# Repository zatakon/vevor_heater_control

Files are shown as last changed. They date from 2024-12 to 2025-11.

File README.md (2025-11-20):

# Vevor Heater Control
Vevor diesel heater control project

---

>## ⚠️ IMPORTANT: You Probably Want the Other Repository!
>
>**This repository is for protocol reverse engineering and research purposes only.**
>
>**If you want a ready-to-use ESPHome library for your Vevor heater, please visit:**
>### 👉 **[https://github.com/zatakon/esphome-vevor-heater](https://github.com/zatakon/esphome-vevor-heater)** 👈
>
>The `esphome-vevor-heater` repository contains a complete, user-friendly ESPHome custom component that you can easily integrate into your Home Assistant setup.

---

## Background

I bought a Vevor diesel heater and put it into my workshop with the intention to keep the temperature above zero during winter. There is a project for communication with Chinese heaters, but this broadly used protocol is unfortunately not used in Vevor ones. Because there was no solution on how to connect Vevor to my Home Assistant ecosystem, I needed to do it by myself.

## 2. Current Status of the Project
The project is now ready to use for all who have some experience with ESPHome. 

### 2.1 HW
This is a simple schematic of how I connected my ESP32 to the bus. \
Be careful and connect the RX transistor to the 3.3V rail, not 5V. \
**Double check the transistors'** pinout. \
Feel free to use any pin for TX and RX. \
**Put pullup resistor between data line and 5V**

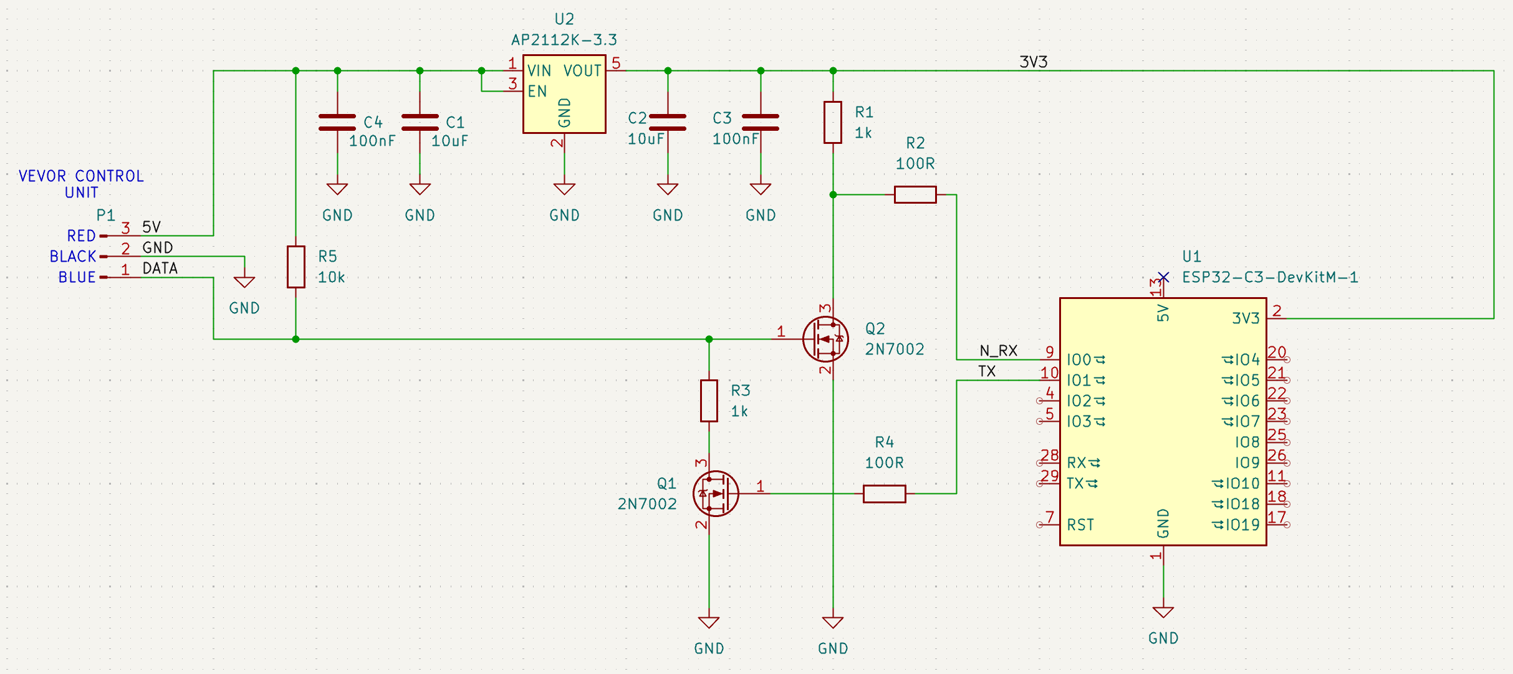
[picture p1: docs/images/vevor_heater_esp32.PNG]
Connection ESP32 to Vevor


### 2.2 SW

1. Open terminal in project folder
```
firmware/esphome/vevor_heater_example
```

2. Install the ESPHome library using pip
```
pip install esphome
```
3. Change the config RNW-ESPHM-C3-MNM-VEVOR/RNW-ESPHM-C3-MNM-VEVOR.yaml to match your board configuration and just run it using this command
```bash
esphome run vevor_heater_example
```

The project for my board is located in the folder firmware/esphome/RNW-ESPHOME-C3-MNM-VEVOR. There are more settings than you need and no temperature sensor. Add one if you want to. 

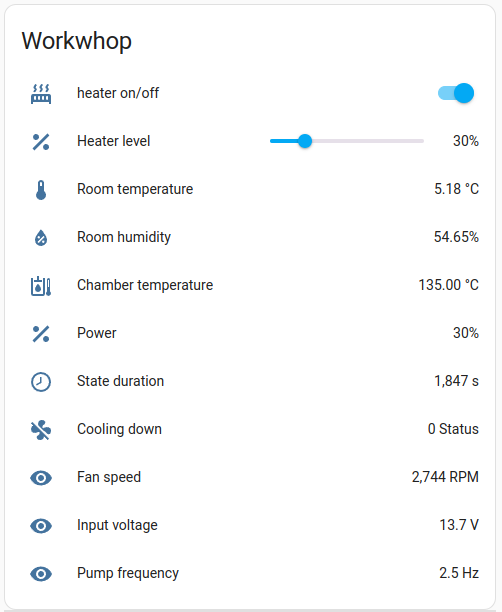
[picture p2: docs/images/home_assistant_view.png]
ESPhome view

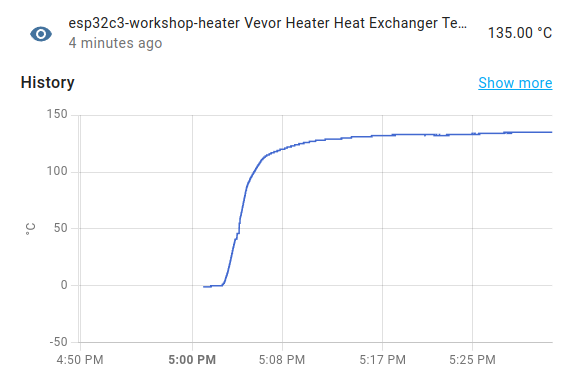
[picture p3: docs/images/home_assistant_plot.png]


A more easy-to-use solution is in the "work in progress" state. I will try to get to it soon. 

## 4. Hardware background
The bus is open drain. The basic voltage is approximately 4V and very noisy (3.3 - 6V). Don't connect directly to any MCU without protection; there is a risk that the magic smoke will escape...

Captured communication looks like this:
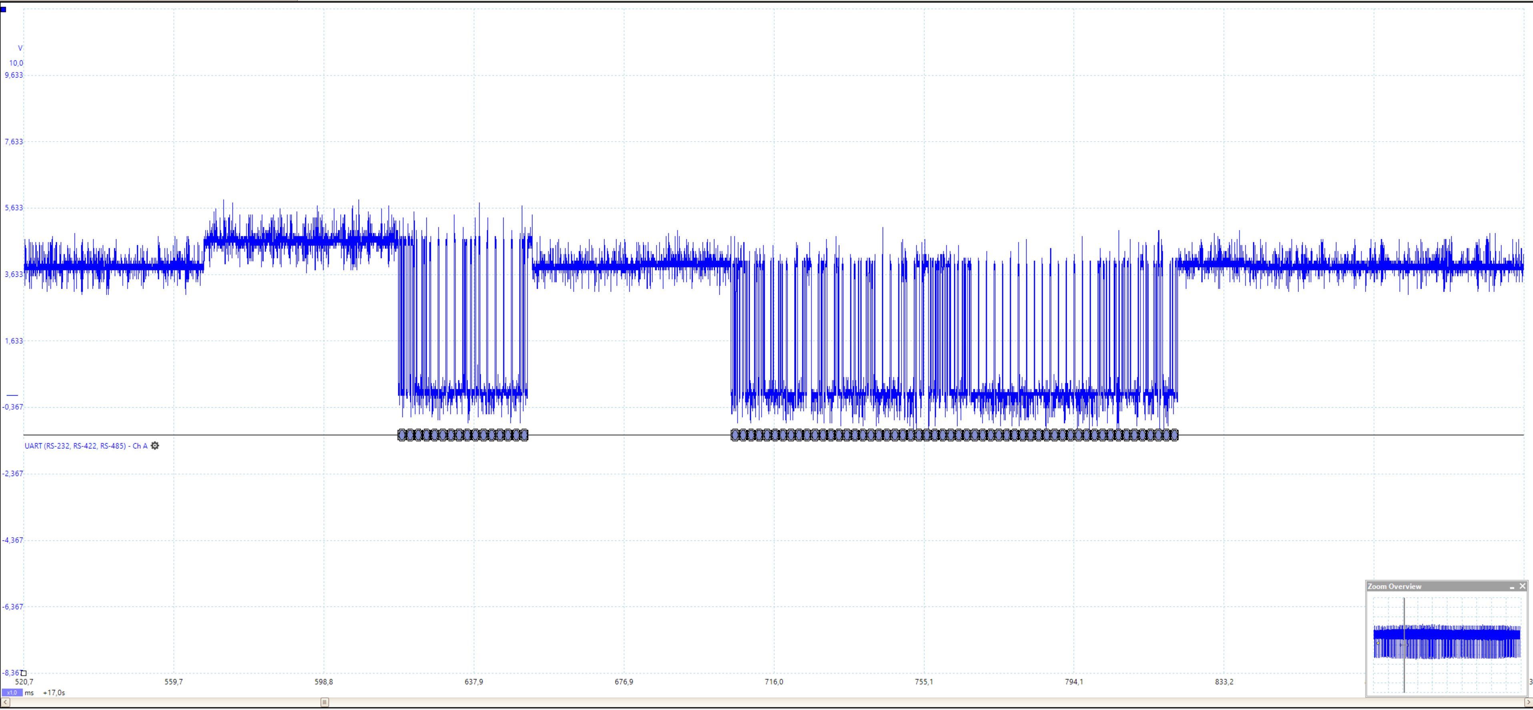
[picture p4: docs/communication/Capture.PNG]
picoscope communication


The hardware seems to be very similar to that described by [Ray Jones](https://gitlab.com/mrjones.id.au/bluetoothheater/-/blob/master/Documentation/V9%20-%20Hacking%20the%20Chinese%20Diesel%20Heater%20Communications%20Protocol.pdf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)
Half-duplex communication using NPN, PNP transistors and an EN pin driving them. 
The CPU in the Vevor controller is most likely 5V tolerant, unlike our ESP32. I created a simple circuit for safe connection between the Vevor bus and my ESP32.

## 5. Software
The controller sends a command to the main unit every second. The unit sends back the current status.
Baud rate is 4.8 kbaud.

### 5.1 Communication Controller -> Main Unit
| Byte  | Certainty | Values | Comment
| --- | --- | --- | ---
| 0: | 100% | 0xAA | Identifier 0xAA
| 1: | 100% | 0x66 | Device ID (controller 0x66, heater 0x77)
| 2: | 50% | 0x02 0x06  | Command? (0x02: get state, 0x06: start up)
| 3: | 100% | 0x0B | Length field (0x0B for controller->heater, 0x33 for heater->controller)
| 4: | 0% | 0x00 | Unknown
| 5: | 0% | 0x00 | Unknown
| 6: | 0% | 0x00 | Unknown
| 7: | 0% | 0x00 | Unknown
| 8: | 100% | 1-10 | Power level [level]
| 9: | 90% | 2, 5, 6, 8 | Requested state (0x02: off, 0x05: cooling down, 0x06: start, 0x08: running) [state]
| 10: | 0% | 0x00 | Unknown
| 11: | 0% | 0x00 | Unknown
| 12: | 0% | 0x00 | Unknown
| 13: | 0% | 0x00 | Unknown
| 14: | 100% | 1-255 | Checksum (sum of byte 2+3+8+9)

### 5.2 Communication Main Unit -> Controller
| Byte  | Certainty | Values | Comment
| --- | --- | --- | ---
| 0: | 100% | 0xAA | Identifier 0xAA
| 1: | 100% | 0x77 | Device ID (controller 0x66, heater 0x77)
| 2: | 50% | 0x02 | Command?
| 3: | 100% | 0x33 | Length field (0x0B for controller->heater, 0x33 for heater->controller)
| 4: | 80% | 0-1 | All 1, last one 0 | Heater enabled?
| 5: | 99% | 0x00-0x04  | State (0x00: off, 0x01: glow plug pre-heat, 0x02: ignited, 0x03: stable combustion, 0x04: stopping, cooling) [state]
| 6: | 100% | 0x01-0x0A  | Power level [level]
| 7: | 90% | 0x00-0x09  | Error reported by Main Unit to Controller (0x00: no error, 0x01: E10 - startup fail, 0x02: E08 - check fuel level, 0x03: E01 - supply voltage overrun, 0x04: E04 - ?, 0x05: E05 - ?, 0x06: E04 - Fuel pump failure, 0x07: E06 - Fan failure,  0x08: E03 - Check ignition, 0x09: E05 - Overheat)
| 8: | 0% | 0x00, 0x03 | 0x03 if running, 0x00 if stopped (just last one is 0)
| 9: | 0% | 0x00, 0xFB | 0xFB if running, 0x00 if stopped (just last one is 0)
| 10: | 0% | 0x00 | Unknown
| 11: | 99% | 153-158 | Input voltage [V * 10]
| 12: | 0% | 0x00 | Unknown
| 13: | 40% | 0-12 | Glow plug current [A]
| 14: | 50% | 0-1 | Cooling down [0/1]
| 15: | 30% | 0-16 | Fan voltage? Some temperature? [V]
| 16-17:| 99% | 480,1630 | Heat exchanger temperature [°C * 100]
| 18: | 0% | 0x00 | Unknown
| 19: | 0% | 0x00 | Unknown
| 20-21:| 90% | 0-325 | State duration [s]
| 22: | 0% | 0x00 | Unknown
| 23: | 90% | 0-51 | Pump frequency [Hz*10]
| 24: | 25% | 0-66 | Glow plug voltage/current/temperature
| 25: | 25% | 0-86 | Glow plug voltage/current/temperature
| 26: | 25% | 0-56 | Glow plug voltage/current/temperature
| 27: | 25% | 0-12 | Glow plug voltage/current/temperature
| 28-29:| 90% | 0-3939 | Fan speed [rpm]
| 30-45:| 0% | 0x00 | Unknown
| 46: | 0% | 35 | Unknown constant
| 47: | 0% | 4 | Unknown constant
| 48: | 0% | 17 | Unknown constant
| 49: | 0% | 35 | Unknown constant
| 50: | 0% | 0x00 | Unknown
| 51: | 0% | 30, 40 | Unknown
| 52-53:| 10% | 0-420 | Something glow plug related
| 54: | 0% | 0x00 | Unknown
| 55: | 100% | 1-254 | Checksum

### 5.2.3. Plot
Use the Python script software/plot_frame.py to visualize values in the frame. You can just run it; the needed data are included in docs. It looks like this:

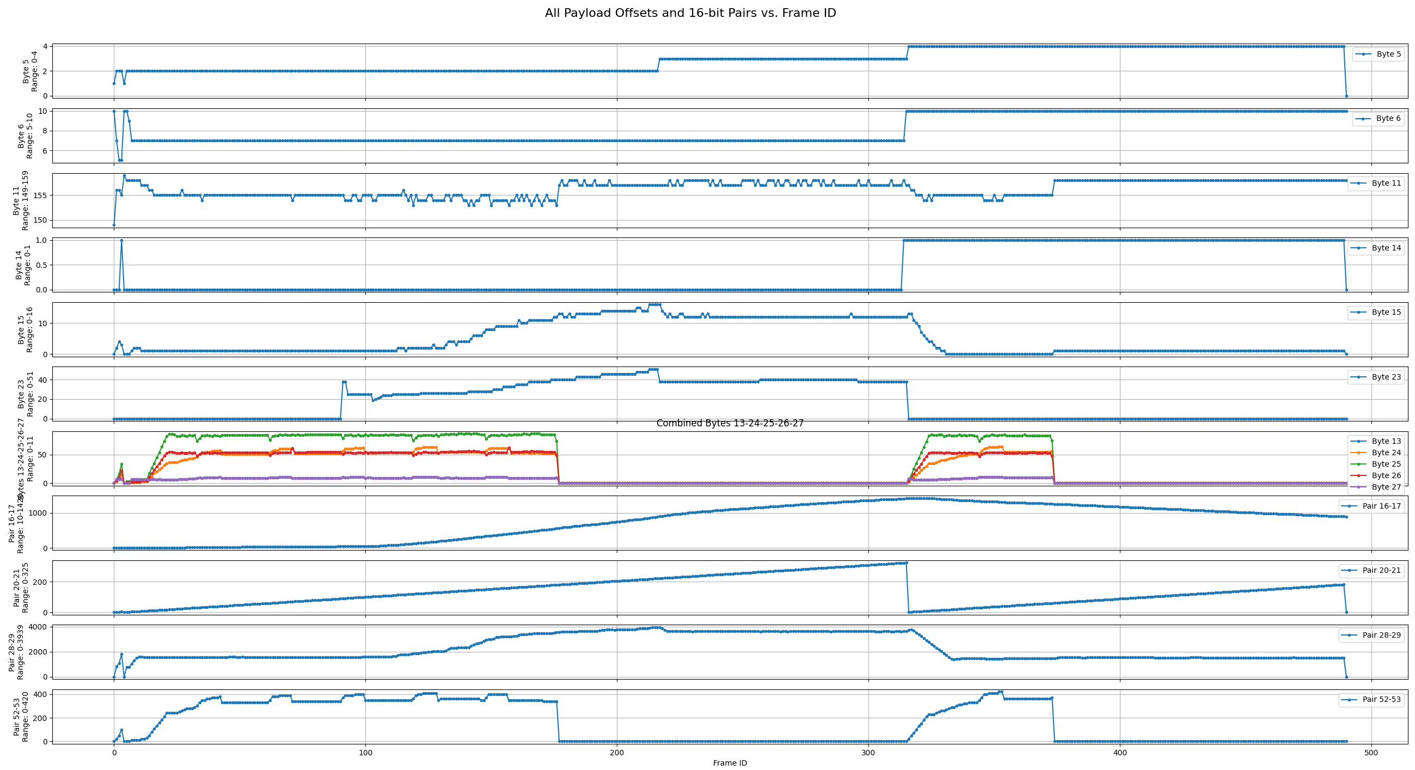
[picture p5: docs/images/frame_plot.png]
Frame plot


## 6. Help needed
A couple of things are missing: 
- altitude compensation
  - should be kind of easy to get from the frame. I have no motivation to do it now :-D
- error reading
  - complicated for me because my device works just fine and I don't want to cause errors. Nevertheless, at least some of them should be easy to get (low battery voltage...?). If someone does it, please let me know and I will implement it.
- device compatibility
  - I have no idea if all Vevor heaters use the same protocol. There is a new generation of Vevor diesel heaters with CO measurement. If someone has it and has tried it, let me know if it works.

Anyway, feel free to make "pull requests" for anything you add to the code please.  

## 7. Ready to Use Device - canceled
~~In case there would be interest in the units which could be used as replacements for basic ones, I am open to this option. But even if I don't need to earn money on this, the units would be comparable in price to the whole diesel heater. But if approximately 60 USD + shipping would make sense for you, feel free to contact me or join the project.~~

~~Edit 22.10.2025: There were a couple of requests for that. I will try to produce a batch of ~20 pieces in the second half of November. But my plans are rarely going according to plan.  
If I manage, I will add a small display, temperature sensor, buttons, and low power mode.~~

**Edit 1.11.2025:** I investigated all possible ways to provide ready-to-use boards. Unfortunately, CE certification is (really) expensive, and there is no legal way to sell such devices without it. Therefore, **ready-made PCBs will not be available.**

j.meindl@seznam.cz

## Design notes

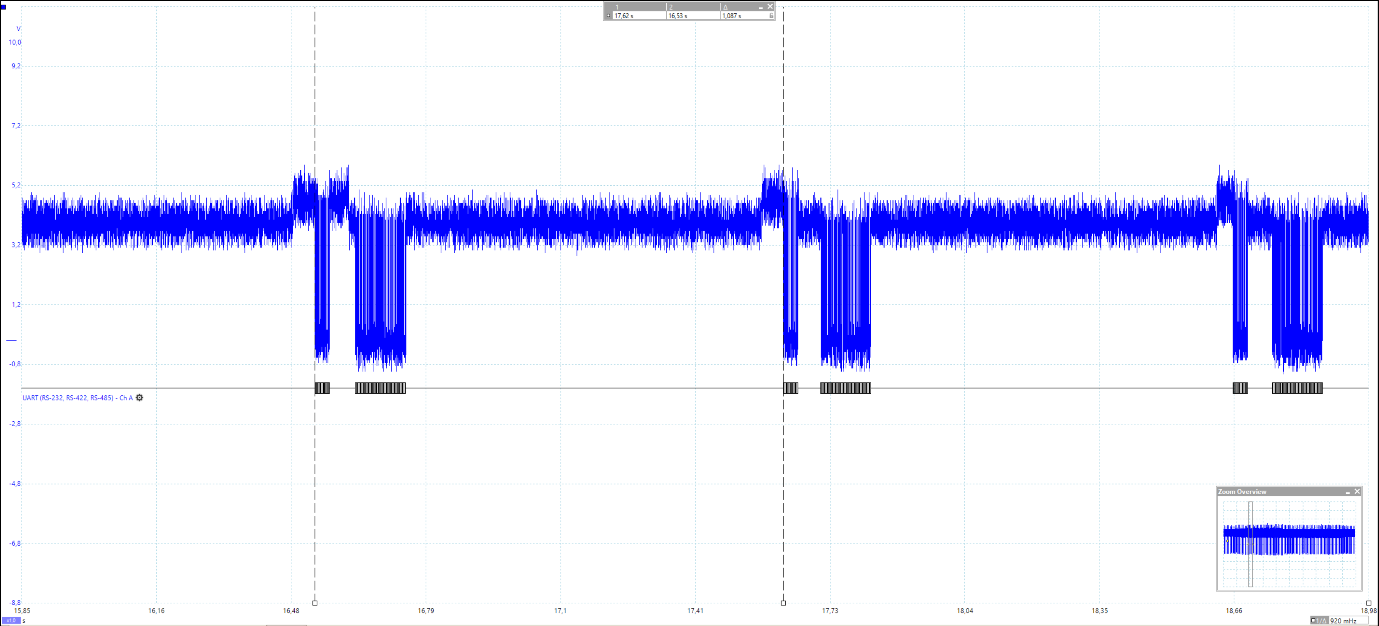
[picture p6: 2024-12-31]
docs/communication/Capture2.PNG

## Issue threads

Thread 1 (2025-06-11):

vevor altitude compensated diesel heater

Cinezaster, 2025-06-11:
Hi, I have the vevor diesel heater with Bluetooth and altitude compensation, build into my campervan.
https://eur.vevor.com/diesel-heater-c_10321/vevor-diesel-air-heater-12v-2kw-bluetooth-app-lcd-display-for-car-bus-rv-indoors-p_010806799987
Would like to add it to my HA.
Curious which model you are working with, could you add a compabiliy list?

I'm currently on vacation, but I will look into this project afterwards.
Can you share pdf of the PCB schematics and circuit? I don't use kicad. I'm currently using easyeda or fusion360.

Thanks for your efforts and sharing it.

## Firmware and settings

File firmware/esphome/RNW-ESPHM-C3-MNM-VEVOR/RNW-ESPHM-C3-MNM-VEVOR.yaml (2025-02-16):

# vevor.yaml

external_components:
  - source: ../components

substitutions:
  id_name: rnw_esphm_c3_01_workshop_heater
  friendly_name: esp32c3-workshop-heater
  update_wifi: 60s
  update_uptime: 60s
  pin_a0: GPIO0
  pin_a1: GPIO1
  pin_a2: GPIO2
  pin_a3: GPIO3
  pin_batt_v: GPIO4
  pin_i2c_scl: GPIO8
  pin_i2c_sda: GPIO7
  pin_d6: GPIO6
  pin_d10: GPIO0
  pin_d18: GPIO8
  pin_btn_pwr: GPIO0
  pin_vin: GPIO1
  pin_chrg_sence: GPIO5
  pin_chrg_state: GPIO9

  # VOLTAGE BATTERY
  batt_capacity_table_size: "11"
  batt_voltage_max: "4.2"
  batt_voltage_min: "3.2"
  batt_r1: "150.0"
  batt_r2: "200.0"
  batt_v: "4.2"

  # VOLTAGE IN
  vin_r1: "200.0"
  vin_r2: "10.0"

esphome:
  name: ${friendly_name}
  friendly_name: ${friendly_name}

esp32:
  board: esp32-c3-devkitm-1
  framework:
    type: arduino

# Enable logging
logger:
  level: DEBUG  # Optional: Set to DEBUG for detailed logs
  baud_rate: 115200
  hardware_uart: UART0

# Enable Home Assistant API
# api:
#   encryption:
#     key: "ww8hNF2Tq7ShF52H5nS4QyEm6+PtV9Alv0DTMEVJv+w="

ota:
  - platform: esphome
    password: "5d88ade2ef43066eeff6d5b1497bbc11"

api:

wifi:
  ssid: !secret wifi_ssid
  password: !secret wifi_password

  # Enable fallback hotspot (captive portal) in case wifi connection fails
  ap:
    ssid: "${friendly_name}"
    password: "IDbWG7CaLYjw"

web_server:
  local: True
  port: 80

captive_portal:

deep_sleep:
  id: deep_sleep_1

i2c:
  id: i2c_0
  scan: false
  sda: ${pin_i2c_sda}
  scl: ${pin_i2c_scl}
  frequency: 400kHz 

uart:
  - id: logger_serial
    tx_pin: GPIO21
    rx_pin: GPIO20
    baud_rate: 115200
  - id: heater_serial
    rx_pin: 
      number: ${pin_a1}
      inverted: true
    tx_pin:
      number: ${pin_a0}
      inverted: true
    baud_rate: 4800

vevorheater:
  id: vevor_heater
  uart_id: heater_serial

  # Define Sensors for Long Frame (main unit -> controller)
  voltage_sensor:
    name: "Vevor Heater Voltage"
    unit_of_measurement: "V"
    accuracy_decimals: 2
  temperature_sensor:
    name: "Vevor Heater Temperature"
    unit_of_measurement: "°C"
    accuracy_decimals: 1
  state_sensor:
    name: "Vevor Heater State"
    device_class: "power"
    icon: "mdi:power"
  power_level_sensor:
    name: "Vevor Heater Power Level"
    unit_of_measurement: "%"
    accuracy_decimals: 0
  fan_speed_sensor:
    name: "Vevor Heater Fan Speed"
    unit_of_measurement: "RPM"
    accuracy_decimals: 0
  pump_frequency_sensor:
    name: "Vevor Heater Pump Frequency"
    unit_of_measurement: "Hz"
    accuracy_decimals: 1
  input_voltage_sensor:
    name: "Vevor Heater Input Voltage"
    unit_of_measurement: "V"
    accuracy_decimals: 1
  glow_plug_current_sensor:
    name: "Vevor Heater Glow Plug Current"
    unit_of_measurement: "A"
    accuracy_decimals: 1
  cooling_down_sensor:
    name: "Vevor Heater Cooling Down"
    unit_of_measurement: "Status"
    icon: "mdi:fan-off"
  # fan_voltage_sensor:
  #   name: "Vevor Heater Fan Voltage"
  #   unit_of_measurement: "V"
  #   accuracy_decimals: 1
  heat_exchanger_temp_sensor:
    name: "Vevor Heater Heat Exchanger Temperature"
    unit_of_measurement: "°C"
    accuracy_decimals: 2
  state_duration_sensor:
    name: "Vevor Heater State Duration"
    unit_of_measurement: "s"
    accuracy_decimals: 0
  # glow_plug_voltage_sensor:
  #   name: "Vevor Heater Glow Plug Voltage"
  #   unit_of_measurement: "V"
  #   accuracy_decimals: 1
  # glow_plug_current_2_sensor:
  #   name: "Vevor Heater Glow Plug Current 2"
  #   unit_of_measurement: "A"
  #   accuracy_decimals: 1
  glow_plug_temperature_sensor:
    name: "Vevor Heater Glow Plug Temperature"
    unit_of_measurement: "°C"
    accuracy_decimals: 1
  # # You can add more sensors based on additional fields

  # Define Sensors for Short Frame (controller -> main unit)
  short_power_level_sensor:
    name: "Vevor Heater Short Frame Power Level"
    # unit_of_measurement: "%"
    # accuracy_decimals: 0
  short_state_sensor:
    name: "Vevor Heater Short Frame State"
    # unit_of_measurement: "State"
    # icon: "mdi:power"
  short_state_text_sensor:
    name: "Vevor Heater Short Frame State Text"
    # icon: "mdi:power"
  # Add more short frame sensors if needed

# Define the Heater Switch (Button) Outside the VevorHeater Component
switch:
  - platform: template
    name: "Heater On/Off"
    id: heater_switch
    optimistic: true
    turn_on_action:
      - lambda: |-
          id(vevor_heater).set_heater_on();
    turn_off_action:
      - lambda: |-
          id(vevor_heater).set_heater_off();

# Define the Heater Level Slider (Number) Outside the VevorHeater Component
number:
  - platform: template
    name: "Heater Level"
    id: heater_level
    min_value: 10
    max_value: 100
    step: 10
    unit_of_measurement: "%"
    icon: "mdi:percent"
    optimistic: true
    set_action:
      - lambda: |-
          id(vevor_heater).set_heater_level(x);
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

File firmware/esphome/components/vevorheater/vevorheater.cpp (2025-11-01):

// vevorheater.cpp
#include "vevorheater.h"

#include "esphome/core/log.h"
#include "esphome/core/hal.h"
#include <cinttypes>

uint8_t calculateChecksum(const std::vector<uint8_t>& frame) {
    // Ensure the frame has at least 3 bytes:
    // - Byte 0: Identifier (0xAA)
    // - Byte 1: Device ID
    // - Byte 2: Start of data
    // - Byte (N-1): Checksum
    if (frame.size() < 4) {
        return 0;
    }
    uint32_t sum = 0;
    // Sum all bytes from index 2 to index (size - 2) inclusive
    for (size_t i = 2; i < frame.size() - 1; ++i) {
        sum += frame[i];
    }
    // Calculate checksum as sum modulo 256
    uint8_t checksum = static_cast<uint8_t>(sum % 256);
    return checksum;
}

namespace esphome {
namespace vevorheater {

static const char *const TAG = "vevorheater.component";

void VevorHeater::setup() {
  ESP_LOGD(TAG, "VevorHeater setup");
  if (!this->uart_) {
    ESP_LOGE(TAG, "UART bus not set!");
    return;
  }
  this->uart_->set_baud_rate(4800);
  this->last_received_time_ = millis(); // Initialize the timestamp

  this->state_ = VevorHeaterState::OFF;
  this->heater_requested_on_ = false;
  this->heater_level_percentage_ = 100;
  this->last_send_time = millis();
}

void VevorHeater::update() {
  bool received_data = false;

  // Read available bytes and add them to the frame buffer
  while (this->uart_->available()) {
    uint8_t data;
    this->uart_->read_byte(&data);
    this->frame_buffer_.push_back(data);
    this->last_received_time_ = millis(); // Update the timestamp
    ESP_LOGD(TAG, "Received byte: 0x%02X", data);
    received_data = true;
  }

  // Check if the timeout has been exceeded and there is data in the buffer
  if (!this->frame_buffer_.empty()) {
    uint32_t current_time = millis();
    if ((current_time - this->last_received_time_) > 10) { // 10 ms timeout
      ESP_LOGD(TAG, "Frame complete. Processing frame of %d bytes.", this->frame_buffer_.size());
      process_frame(this->frame_buffer_);
      this->frame_buffer_.clear(); // Clear the buffer for the next frame
    }
  }

  uint32_t now = millis();
  if (now - last_send_time >= 1000) {
    last_send_time = now;
    
    // Only send frames if heater is not already off and stable
    // This allows continued communication during cooldown phase
    bool should_send_frame = true;
    if (!heater_requested_on_ && this->state_ == VevorHeaterState::OFF) {
      should_send_frame = false;
    }
    
    if (should_send_frame) {
      std::vector<uint8_t> short_frame;
      // if heater is requested to be off
      if (!heater_requested_on_) {
        if (this->state_ != VevorHeaterState::STOPPING_COOLING) {
        // Send short frame to turn heater OFF
        short_frame.push_back(0xAA); 
        short_frame.push_back(0x66); 
        short_frame.push_back(0x06); 
        short_frame.push_back(0x0B);
        short_frame.push_back(0x00);
        short_frame.push_back(0x00);
        short_frame.push_back(0x00);
        short_frame.push_back(0x00);
        short_frame.push_back(10);
        short_frame.push_back(0x05);
        short_frame.push_back(0x00);
        short_frame.push_back(0x00);
        short_frame.push_back(0x00);
        short_frame.push_back(0x00);
        short_frame.push_back(0x00);
        uint8_t checksum = calculateChecksum(short_frame);
        short_frame.push_back(checksum);
        
        this->uart_->write_array(short_frame.data(), short_frame.size());
        ESP_LOGD(TAG, "Sent short frame to set level %u%%", this->heater_level_percentage_);
      } else {
        // Send short frame to keep heater shutting OFF
        short_frame.push_back(0xAA); 
        short_frame.push_back(0x66); 
        short_frame.push_back(0x02); 
        short_frame.push_back(0x0B);
        short_frame.push_back(0x00);
        short_frame.push_back(0x00);
        short_frame.push_back(0x00);
        short_frame.push_back(0x00);
        short_frame.push_back(10);
        short_frame.push_back(0x02);
        short_frame.push_back(0x00);
        short_frame.push_back(0x00);
        short_frame.push_back(0x00);
        short_frame.push_back(0x00);
        short_frame.push_back(0x00);
        uint8_t checksum = calculateChecksum(short_frame);
        short_frame.push_back(checksum);
        
        this->uart_->write_array(short_frame.data(), short_frame.size());
        ESP_LOGD(TAG, "Sent short frame to set level %u%%", this->heater_level_percentage_);
      }
    // if heater is requested to be on
    } else {
      if (this->state_ == VevorHeaterState::OFF) {
        // Send short frame to turn heater ON
        short_frame.push_back(0xAA); 
        short_frame.push_back(0x66); 
        short_frame.push_back(0x06); 
        short_frame.push_back(0x0B);
        short_frame.push_back(0x00);
        short_frame.push_back(0x00);
        short_frame.push_back(0x00);
        short_frame.push_back(0x00);
        short_frame.push_back(this->heater_level_percentage_/10);
        short_frame.push_back(0x06);
        short_frame.push_back(0x00);
        short_frame.push_back(0x00);
        short_frame.push_back(0x00);
        short_frame.push_back(0x00);
        short_frame.push_back(0x00);
        uint8_t checksum = calculateChecksum(short_frame);
        short_frame.push_back(checksum);

        this->uart_->write_array(short_frame.data(), short_frame.size());
        ESP_LOGD(TAG, "Sent short frame to turn heater ON with level %u%%", this->heater_level_percentage_);
      } else {
        // Send short frame to keep heater ON
        short_frame.push_back(0xAA); 
        short_frame.push_back(0x66); 
        short_frame.push_back(0x02); 
        short_frame.push_back(0x0B);
        short_frame.push_back(0x00);
        short_frame.push_back(0x00);
        short_frame.push_back(0x00);
        short_frame.push_back(0x00);
        short_frame.push_back(this->heater_level_percentage_/10);
        short_frame.push_back(0x08);
        short_frame.push_back(0x00);
        short_frame.push_back(0x00);
        short_frame.push_back(0x00);
        short_frame.push_back(0x00);
        short_frame.push_back(0x00);
        uint8_t checksum = calculateChecksum(short_frame);
        short_frame.push_back(checksum);
        
        this->uart_->write_array(short_frame.data(), short_frame.size());
        ESP_LOGD(TAG, "Sent short frame to set level %u%%", this->heater_level_percentage_);
      }
    }
    }
  }

  // Handle Heater Control based on internal state
//   if (heater_requested_on_) {
//         // Send short frame once per second with current heater level
//         static uint32_t last_send_time = 0;
//         uint32_t now = millis();
//         if (now - last_send_time >= 1000) { // 1 second interval
//         last_send_time = now;
//         std::vector<uint8_t> short_frame;
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

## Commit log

2024-12-31 init commit for esphome project. Communication reading.
    [controller_schematics.kicad_sch]
2024-12-31 Adedd fiels for frame parsing
2025-01-02 Updated frame vizualization
2025-01-08 Reading from controller works
    [controller_schematics.kicad_sch, custom_control.kicad_sch]
2025-01-19 Updated HW design for connecting to the bus
    [custom_control.kicad_sch]
2025-02-16 Added remote control ability. Now starting the heater remotely is possible as well as reading main status values. Changed folder structure.
2025-10-22 Updated schematics to make it more clear
    [custom_control.kicad_sch]
2025-10-23 Fixed issue in schematics made in last commit. Changed readme to be more clear.
    [custom_control.kicad_sch]
2025-10-27 Added missing pull-up in schematics
    [custom_control.kicad_sch]
2025-11-01 Add warning to direct users to esphome-vevor-heater repo
2025-11-01 Update ready-to-use device section
2026-10-26 docs: correct frame layout from the captured log, list other Vevor protocols
    The captured log of the original controller
    (docs/communication/log_start_running_stop.txt, 974 frames) shows:
    - controller frames are 16 bytes, byte 14 is 0x00 and the checksum is
    byte 15 (the table had 15 bytes with the checksum in byte 14)
    - total length is the length field + 5 for both directions, and the
    checksum sum(bytes 2..n-2) mod 256 matches every frame
    - byte 9 = 0x05 is the stop request, sent once with command 0x06
    - heat exchanger temperature is degC * 10 (480-1630 = 48-163 degC), signed
    Device compatibility now lists the tested XMZ-D2 heaters and points to
    the PWM-style variant (kellerman/vevor_pw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
